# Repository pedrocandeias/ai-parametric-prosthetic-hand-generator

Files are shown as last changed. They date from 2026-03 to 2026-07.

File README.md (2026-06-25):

# AI Parametric Prosthetic Hand Generator

**🌐 Languages: English · [Português](README.pt.md)**

**🔗 Live: [handfab.pedrocandeias.net](https://handfab.pedrocandeias.net)**

AI-powered parametric prosthetic hand customisation platform. Clinicians enter a patient's anthropometric measurements; an AI model (Claude or GPT-4) suggests optimal design parameters; the result renders in-browser via WebAssembly and exports as STL for 3D printing.

Built on [OpenSCAD](https://openscad.org/) and the [OpenSCAD Playground](https://github.com/openscad/openscad-playground) WASM runtime.

---

## Features

- **In-browser 3D rendering** — OpenSCAD runs entirely in WebAssembly; no server round-trip for rendering
- **AI parameter suggestions** — Claude or GPT-4 analyses anthropometric input and recommends parameter values
- **Six canonical anthropometric parameters** — all models share the same measurement definitions (`palm_breadth_mm`, `palm_length_mm`, `palm_thickness_mm`, `middle_finger_length_mm`, `thumb_length_mm`, `gauntlet_width_mm`) so patient profiles auto-populate model inputs
- **Saved configurations** — named parameter sets stored per patient; load across sessions
- **Multi-user RBAC** — Admin / Tech / User roles; techs manage assigned patients
- **Secure API proxy** — AI keys live server-side only
- **STL export** — download print-ready files directly from the browser; models with defined parts offer a selection modal to export the whole model or individual parts (multiple parts download as a ZIP). On the Flexy Beast, each finger splits into a separate **base** and **tip** piece so every printable component can be exported and oriented on its own
- **Admin SCAD code editor** — admins can hand-edit OpenSCAD source and render immediately
- **Anthropometric profile library** — import population-level hand measurement datasets; geometry parameters are auto-derived and mapped to model inputs
- **Bulk CSV import** — load a population hand-measurement dataset (e.g. the `multi_population_hand.csv` research dataset, ~96 groups) through your browser's file picker in one click. The import reads the file locally and uploads its contents; re-running is safe (duplicate groups are skipped)
- **Multilingual (EN/PT)** — a language switcher translates the whole interface (app, configurator, admin panel) and the model/parameter text; the active language is detected from the browser and remembered. Adding a language is a single dictionary file
- **Editable footer & content pages (CMS)** — admins manage the footer and create Markdown pages (Privacy, Terms, Help, …) from the Admin Panel; pages render at clean `/pages/<slug>` URLs, and each page can be translated into a linked per-language version

---

## Available Models

| Model | ID | Parameters | Notes |
|---|---|---|---|
| **Flexy Beast** | `flexy_beast` | All anthropometric params + flexy-joint hardware + grip pads + forearm gauntlet | Fully parametric, self-contained — no external STL imports |
| **UnLimbited Phoenix Hand V1.0** | `unlimbed_phoenix_hand` | Uniform print scale derived from `palm_breadth_mm` (Team UnLimbited HandPerc); per-part selector | STL-derived meshes; 8 printable pieces (palm, fingers, phalanx, pins, tension box/pins, gauntlet, jig) |
| **Paraglider Hand (Flexible Flyer)** | `paraglider_hand` | All anthropometric params + per-finger scaling + assembled/print-layout views + `show_*` part toggles | Parametric fingers; palm imports a repaired Phoenix v2 mesh as its base body |
| **Paraglider variants & accessories** | `paraglider_palm_v3`, `paraglider_palm_reborn_tensor`, `paraglider_palm_v3_tensor`, `paraglider_tensioner_box`, `paraglider_thermo_gauntlet`, `paraglider_unlimbited_arm` | Palm variants (Phoenix Reborn / UnLimbited v3, integrated-tensioner), tensioner box, thermoform gauntlet, elbow-powered arm | Marcus Mendenhall's Paraglider remix family; uniform print scale from canonical `palm_breadth_mm` (the arm keeps native `HandLen` mm) |

---

## Requirements

- **Node.js ≥ 22** — the database uses Node's built-in `node:sqlite`, so no native module needs compiling
- An Anthropic or OpenAI API key (for AI suggestions; the app works without one but the suggestion button is disabled)

---

## Getting Started

### 1. Install

```bash
git clone <repo>
cd ai-parametric-prosthetic-hand-generator
npm install
```

### 2. Configure

```bash
cp .env.example .env
```

Edit `.env`:

```env
JWT_SECRET=<run: node -e "console.log(require('crypto').randomBytes(32).toString('hex'))">
ANTHROPIC_API_KEY=sk-ant-...
OPENAI_API_KEY=sk-...
PORT=3000
NODE_ENV=production
```

`JWT_SECRET` is required — the server will not start without it.

### 3. Start

```bash
npm start          # production
npm run dev        # development (auto-restarts on file change)
```

### 4. First-run setup

Navigate to `http://localhost:3000`. The app shows a **First-Run Setup** form — create the admin account. You can then create tech and user accounts from the Admin Panel.

**CLI alternative:**

```bash
node scripts/create-admin.js admin admin@example.com MyPassword123
```

---

## Deployment

The app is a single Node.js process that serves both the REST API and the static
frontend, so deploying means shipping the source tree (minus secrets, the dev
database, and `node_modules`) and running `npm ci` + `npm start` on the server.

The live site runs on **cPanel + Phusion Passenger** (Node 24). There is no build
step — `app.js`, `models/`, and the `.scad` files ship as-is. The everyday deploy
is a single command:

```bash
./deploy.sh deploy --dry-run     # preview exactly what will transfer (no changes)
./deploy.sh deploy               # → configured cPanel target, after a remote DB+code backup
```

With **no destination** it uses the configured cPanel target; the script stages
the tree, takes a remote backup (DB + code tarball), then rsyncs. Useful flags:
`--port N` (SSH port), `--yes` (skip the confirm prompt), `--delete` (mirror —
removes stale remote files, use with care). To target a different host, pass
`user@host:/path` explicitly. Use `./deploy.sh collect --tar` to stage a
`deploy.tar.gz` locally without uploading.

The package **excludes** secrets (`.env`), the dev SQLite DB (`data/`),
`node_modules`, `.git`, tests, and — critically — the server-managed
**`.htaccess`** (it holds the Passenger config and the COOP/COEP headers the
OpenSCAD WASM needs). A post-stage safety check aborts if a secret or `data/`
slips through. `.env.example` *is* included as a template.

**After a deploy:** client-only changes (`app.js`, `index.html`, `models/`,
`.scad`) are live as soon as the browser refetches. Changes under `server/**`
need a **Restart** in the cPanel "Setup Node.js App" panel; new dependencies also
need **Run NPM Install** there.

First-time server setup (create the cPanel Node app, set `JWT_SECRET` + API keys,
`npm ci`, `create-admin`) and a pm2 + Nginx VPS alternative are covered in
[DEPLOYMENT.md](DEPLOYMENT.md) and [DEPLOY-QUICKSTART.md](DEPLOY-QUICKSTART.md).

---

## Project Structure

```
/
├── index.html                  Main UI
├── auth.js                     Frontend auth (token in memory, refresh cookie)
├── app.js                      ParameterEditor — rendering, UI, save/load
├── admin.html / admin.js       Admin panel (users, anthropometric, footer & pages)
├── anthropometric.js           Anthropometric importer modal (admin)
├── openscad-worker.js          WASM rendering worker
├── page.html                   Public Markdown content-page viewer (/pages/<slug>)
├── i18n.js / translations.js   Lightweight i18n core + EN/PT dictionaries
├── footer.js                   Renders the editable footer from the API
├── markdown.js                 Tiny safe Markdown → HTML renderer
│
├── models/
│   ├── models-config.json                  Model registry + parameter specs (with _pt translations)
│   └── active/
│       ├── flexy_beast/                     Flexy Beast — self-contained parametric SCAD
│       ├── unlimbed_phoenix_hand/           UnLimbited Phoenix Hand — STL-derived, per-part export
│       ├── paraglider_hand/                 Paraglider Hand — parametric SCAD + palm mesh base
│       └── paraglider/                      Paraglider variants & accessories (palms, tensioner, gauntlet, arm)
│
├── docs/                           Model notes + anthropometric validation
│
├── data/                          (gitignored — created/supplied locally, not in the repo)
│   ├── app.db                      SQLite DB (auto-created on first run)
│   └── multi_population_hand.csv   Population hand measurements (~96 groups; supply separately)
│
├── server/
│   ├── index.js                Express server entry point
│   ├── db.js                   node:sqlite connection (auto-migrates)
│   ├── schema.sql              DB schema
│   ├── middleware/             auth.js, errorHandler.js
│   ├── routes/                 setup, auth, users, configs, ai, anthropometric, content
│   └── services/              authService.js, aiService.js, anthropometricImporter.js
│
├── scripts/
│   ├── create-admin.js         CLI admin creation
│   └── seed-content.js         Seed/refresh the footer + content pages
│
├── CLAUDE.md                   Developer guide for Claude Code
├── CHANGELOG.md                Version history
├── .env.example                Environment template
└── package.json
```

---

## User Roles

| Role | Capabilities |
|---|---|
| **admin** | Full access: manage users, view all configs, tech assignments, SCAD code editor |
| **tech** | Own configs + read/write configs for assigned patients |
| **user** | Own saved configurations only |

---

## Anthropometric Parameters

All models that support auto-population from patient profiles use these canonical parameter names:

| Parameter | Measurement | Typical adult range |
|---|---|---|
| `palm_breadth_mm` | Knuckle-to-knuckle metacarpal breadth | 70–100 mm |
| `palm_length_mm` | Wrist base to MCP knuckle line | 90–120 mm |
| `palm_thickness_mm` | Palmar to dorsal surface | 22–38 mm |
| `middle_finger_length_mm` | MCP crease to middle fingertip | 60–100 mm |
| `thumb_length_mm` | Thumb MCP crease to tip | 45–80 mm |
| `gauntlet_width_mm` | Forearm socket width (≈ wrist circumference / π) | 40–90 mm |

These names must match exactly in `.scad` files and `models-config.json` so patient profiles imported from CSV auto-populate the correct fields.

### Importing the population dataset

The dataset CSV is **not bundled in the repo** (`data/` is gitignored). Obtain
`multi_population_hand.csv` separately and place it anywhere on your machine first.

1. Log in as admin → open **Admin Panel**
2. Go to **Anthropometric Profiles** tab
3. Click **⬆ Import CSV Dataset** — your browser opens a file picker. Browse to wherever you
   saved `multi_population_hand.csv` (in this project it lives at `data/`) and choose it. The
   file is read locally in the browser and its contents are uploaded; the app does not fetch it
   by path.
4. A confirmation shows how many profiles were created (re-importing is safe — duplicate groups
   are skipped)

> The CSV must conform to the bulk-import schema (columns `measurement_name`, `population`,
> `country`, `sex`, `age_group`, `stat_type`, `value_mm`, …); only `mean` rows are imported.
> See [docs/ai_anthropometric_validation.md](docs/ai_anthropometric_validation.md) Appendix C
> for the full pipeline.

---

## Adding a Model

1. Place your `.scad` file in `models/`
2. Add an entry to `models/models-config.json`:

```json
{
  "id": "my_model",
  "name": "My Prosthetic Model",
  "description": "...",
  "file": "my_model.scad",
  "parameters": [
    {
      "name": "palm_breadth_mm",
      "type": "number",
      "initial": 83,
      "min": 55,
      "max": 110,
      "step": 1,
      "caption": "Knuckle-to-knuckle palm breadth (mm)",
      "group": "Anthropometric"
    }
  ]
}
```

3. Restart the server — the model appears in the dropdown immediately.

**Parameter types:**

| Type | Control | Notes |
|---|---|---|
| `number` with `min`/`max` | Slider | |
| `number` without `min`/`max` | Number input | |
| `boolean` | Checkbox | |
| `string` | Text input | |

If the model references external STL files via `import()` or `use<>`, list them under `dependencies`:

```json
"dependencies": [
  { "url": "subdir/part.stl", "path": "part.stl" }
]
```

The `url` is relative to `models/` on the server; `path` is where the file lands in the WASM virtual filesystem (must be flat — no subdirectories).

---

## API Overview

| Endpoint | Description |
|---|---|
| `GET /api/setup/status` | First-run check |
| `POST /api/setup/admin` | Create first admin |
| `POST /api/auth/login` | Login |
| `POST /api/auth/register` | Self-register |
| `POST /api/auth/refresh` | Rotate tokens via cookie |
| `POST /api/auth/logout` | Revoke refresh token |
| `GET /api/users` | List users (admin) |
| `POST /api/users` | Create user (admin) |
| `GET /api/configurations` | List accessible configs |
| `POST /api/configurations` | Save config |
| `PUT /api/configurations/:id` | Update config |
| `DELETE /api/configurations/:id` | Delete config |
| `POST /api/ai/suggest` | AI parameter suggestion proxy |
| `GET /api/anthropometric` | List anthropometric profiles (admin) |
| `POST /api/anthropometric` | Create profile from manual/CSV/JSON (admin) |
| `POST /api/anthropometric/import-csv-bulk` | Bulk-import population CSV (admin) |
| `GET /api/anthropometric/:id` | Fetch profile with derived geometry params |
| `PUT /api/anthropometric/:id` | Update profile |
| `DELETE /api/anthropometric/:id` | Delete profile |
| `GET /api/content/footer` · `PUT` | Read footer config (public) / save (admin) |
| `GET /api/content/pages/:slug?lang=` | Public content page, language-aware |
| `POST/PUT/DELETE /api/content/pages` | Manage content pages (admin) |
| `POST /api/content/pages/:id/translate` | Create a linked translation of a page (admin) |

**Rate limits:** login 5/15 min · register 3/hr · AI suggestions 10/min · all others 500/15 min

---

## Security

- Passwords hashed with bcrypt (cost 12)
- JWT access tokens: 15-minute expiry, stored in JS memory only (never localStorage)
- Refresh tokens: 7-day expiry, stored as SHA-256 hashes, rotated on every use
- `/.env` and `/config.json` return 404 — blocked before static middleware
- All request bodies validated with Zod
- Helmet CSP headers
- AI API keys never leave the server

---

## Configuration Reference

| Variable | Required | Description |
|---|---|---|
| `JWT_SECRET` | Yes | 64-char hex string for JWT signing |
| `ANTHROPIC_API_KEY` | For AI | Claude API key |
| `OPENAI_API_KEY` | For AI | OpenAI API key |
| `PORT` | No | HTTP port (default: 3000) |
| `NODE_ENV` | No | `development` or `production` |

---

## Password Reset (CLI)

```bash
node -e "
const db = require('./server/db');
const bcrypt = require('bcrypt');
const hash = bcrypt.hashSync('newpassword', 12);
db.prepare('UPDATE users SET password_hash = ? WHERE username = ?').run(hash, 'admin');
console.log('done');
"
```

---

## Credits

- [OpenSCAD Playground](https://github.com/openscad/openscad-playground) — WASM rendering runtime
- [OpenSCAD](https://openscad.org/) — parametric 3D modelling language
- [Flexy Beast](https://www.thingiverse.com/thing:380665) by daprice — a mashup of the Parametric Cyborg Beast and the Flexy Hand
- [Team UnLimbited](https://www.thingiverse.com/thing:1672381) — UnLimbited Arm / Phoenix Hand designs
- [e-NABLE](https://enablingthefuture.org) — open-source prosthetic hand designs (Phoenix / Unlimbited lineage behind the Paraglider Hand)

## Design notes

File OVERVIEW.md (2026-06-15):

# Project Overview

## What This Project Does

A web application for clinicians and prosthetists to:

1. Load parametric OpenSCAD prosthetic hand models
2. Edit parameters using auto-generated sliders, checkboxes, and inputs
3. Preview the 3D model in real-time (rendered in-browser via OpenSCAD WebAssembly)
4. Get AI-suggested parameter values from a patient's anthropometric data
5. Save named configurations per patient and load them later
6. Export customised models as STL files ready for 3D printing — whole model or individual print pieces (on the Flexy Beast, each finger as a separate base and tip)

Multi-user support with three roles: **Admin**, **Tech** (prosthetist), and **User** (patient). Techs can see and edit configurations for their assigned patients.

---

## Architecture at a Glance

```
┌──────────────────────────────────────────────────┐
│  Browser                                          │
│                                                   │
│  index.html  auth.js  app.js  openscad-worker.js  │
│   (UI)       (auth)  (logic)  (WASM rendering)    │
└───────────────────┬──────────────────────────────┘
                    │  HTTP/REST
┌───────────────────▼──────────────────────────────┐
│  Node.js / Express  (server/index.js)             │
│                                                   │
│  /api/setup  /api/auth  /api/users                │
│  /api/configurations  /api/ai  /api/anthropometric│
│                                                   │
│  Helmet · Rate limits · Cookie parser             │
└──────────┬──────────────────┬────────────────────┘
           │                  │
    ┌──────▼──────┐    ┌──────▼──────┐
    │  SQLite DB  │    │  AI APIs    │
    │  data/app.db│    │  Anthropic  │
    │             │    │  OpenAI     │
    └─────────────┘    └─────────────┘
```

**Key design decisions:**

- OpenSCAD rendering is 100% client-side (WebAssembly). No server load for 3D rendering.
- The server handles auth, persistence, and AI proxying only.
- AI API keys are server-side only — clients never see them.
- Access tokens live in JavaScript memory (not localStorage) for XSS resistance.
- Refresh tokens are stored in HttpOnly cookies (CSRF-resistant via SameSite=Strict).

---

## Key Components

### Frontend

| File | Purpose |
|---|---|
| `index.html` | Single-page app shell — login modal, sidebar, 3D viewer |
| `auth.js` | `Auth` singleton: login, logout, token storage, silent refresh, `fetchWithAuth` |
| `app.js` | `ParameterEditor` class: model loading, parameter UI, rendering, save/load configs |
| `admin.html` / `admin.js` | Admin panel: user management, tech assignments |
| `openscad-worker.js` | Web Worker that runs OpenSCAD WASM for rendering |

### Backend

| File | Purpose |
|---|---|
| `server/index.js` | Express app — security middleware, route mounting, static serving |
| `server/db.js` | SQLite connection, auto-applies `schema.sql` on startup |
| `server/services/authService.js` | bcrypt hashing, JWT sign/verify, refresh token management |
| `server/middleware/auth.js` | `requireAuth` and `requireRole()` middleware factories |
| `server/routes/setupRoutes.js` | First-run admin creation (hard-gated) |
| `server/routes/authRoutes.js` | login, register, logout, refresh, me |
| `server/routes/userRoutes.js` | User CRUD + tech-patient assignments |
| `server/routes/configRoutes.js` | Saved configuration CRUD with ownership enforcement |
| `server/routes/aiRoutes.js` | Authenticated proxy to Anthropic/OpenAI |
| `server/routes/anthropometricRoutes.js` | Anthropometric profile CRUD + CSV/JSON import (admin) |
| `server/services/aiService.js` | Server-side HTTPS calls to AI providers |
| `server/services/anthropometricImporter.js` | Parses measurement datasets, derives geometry parameters |

### Data

| Table | Purpose |
|---|---|
| `users` | Accounts (username, email, bcrypt hash, role, active flag) |
| `tech_assignments` | Many-to-many tech ↔ patient relationships |
| `configurations` | Named saved parameter sets (JSON blob per row) |
| `refresh_tokens` | Hashed refresh tokens with expiry and revocation |
| `anthropometric_profiles` | Population/patient hand measurements + derived geometry |
| `password_reset_tokens` | One-time, hashed password-reset tokens with expiry |

---

## User Roles

| Role | Can do |
|---|---|
| **admin** | Manage all users, view/edit all configs, assign techs to patients |
| **tech** | View and edit configs for their assigned patients + own configs |
| **user** | View and edit own configs only |

---

## AI Integration

AI calls originate from the **server**, not the browser. The flow is:

1. User types anthropometric data (e.g. `woman, 42yo, 172cm, 75kg, arm 65cm`)
2. `app.js` builds a prompt including current model parameters
3. POST `/api/ai/suggest` — server authenticates the user, applies rate limit
4. `server/services/aiService.js` calls Anthropic or OpenAI using env-var API keys
5. JSON parameter suggestions are returned to the browser and applied to the UI

API keys are read from `process.env` only and are never sent to the client.

---

## OpenSCAD Rendering

Rendering is fully client-side:

1. Parameter controls update the OpenSCAD source code string (in memory)
2. The code is sent to `openscad-worker.js` via `postMessage`
3. The worker runs OpenSCAD WASM, outputs an `.off` mesh
4. `app.js` converts the `.off` to a `.glb` binary
5. `<model-viewer>` displays the result with camera controls

No server involvement. Typical render time: 500ms – 3000ms depending on model complexity.

---

## Technology Stack

| Layer | Technology |
|---|---|
| Runtime | Node.js ≥ 22 |
| HTTP framework | Express 4 |
| Database | SQLite via Node's built-in `node:sqlite` |
| Auth | bcrypt + JWT (HS256) + HttpOnly cookies |
| Validation | Zod |
| Security headers | Helmet |
| Rate limiting | express-rate-limit |
| 3D rendering | OpenSCAD WebAssembly + Google model-viewer |
| Frontend | Vanilla JavaScript (no framework) |

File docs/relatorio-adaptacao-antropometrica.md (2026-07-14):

# Relatório — Adaptação paramétrica dos modelos aos dados antropométricos

**Projeto:** AI Parametric Prosthetic Hand Generator
**Âmbito:** análise técnica detalhada do que foi **adicionado e modificado** em cada modelo ativo da plataforma para que (a) fiquem paramétricos e (b) os dados antropométricos do paciente lhes possam ser aplicados.
**Exclusão:** este relatório não cobre o modelo **pec Phoenix** (por indicação; tem relatório próprio em `docs/pec-phoenix-hand/`).

> As afirmações citam ficheiros reais e versões do `CHANGELOG.md`. A história git está compactada em poucos commits, pelo que a atribuição de versões usa os blocos datados do CHANGELOG (a fonte fiável), cruzados com o conteúdo atual dos ficheiros.

---

## 1. Contexto e problema

Os modelos herdados são reconstruções de designs da comunidade e-NABLE (Flexy Beast, Cyborg Beast, UnLimbited Phoenix, Paraglider/Flexible Flyer). No estado original **não** consumiam medições antropométricas: apresentavam escala fixa ou hardcoded, nomes de parâmetro incompatíveis com o pipeline de importação, e acoplamentos escondidos (partes com escala congelada dentro de sub-ficheiros, percursos de dimensionamento com limites inconsistentes).

O trabalho tornou cada modelo **paramétrico e ancorado na anatomia do paciente**, mantendo os **nomes de campo canónicos** de `CLAUDE.md` (secção *Anthropometric Parameter Alignment*), de forma a que um perfil importado (CSV → base de dados) auto-preencha os parâmetros corretos.

Duas estratégias de parametrização emergiram, consoante a natureza da geometria herdada:
- **Geometria própria escalável** (Flexy Beast, Cyborg Beast) — reconstruída em SCAD paramétrico; a escala aplica-se diretamente às primitivas.
- **Meshes fixas importadas** (UnLimbited Phoenix; a palma do Paraglider) — a camada paramétrica é construída *à volta* das meshes sem distorcer as zonas funcionais (furos de pino), esticando só bandas sem furos.

---

## 2. A ponte de dados — `server/services/profileMapping.js`

O elo entre o **perfil antropométrico armazenado** e o **modelo paramétrico vivo** é `profileMapping.js` — a **única fonte de verdade** desta tradução, usada tanto pelo seletor "Population baseline" da configuração como pelo grounding da IA (`aiRoutes.js`).

**Decisão de arquitetura chave:** o mapeamento parte da árvore anatómica normalizada `profile.measurements` (ex.: `palm.width_mm`, `digits.middle.total_length_mm`) e **não** dos `geometry_parameters` do importador. Estes foram construídos para o design socket-and-phalanx Kwawu/cyborgbeast (chaves como `finger_length_index`, bloco `pekwawu`) e **nenhum** coincide com os nomes canónicos dos modelos. A `profile.measurements` alinha 1:1 com a coluna "Platform source" de `CLAUDE.md`.

Mapa canónico (`PARAM_TO_MEASUREMENT_PATH`):

| Parâmetro do modelo | Caminho em `profile.measurements` |
|---|---|
| `palm_breadth_mm` | `palm.width_mm` |
| `palm_length_mm` / `palm_thickness_mm` | `palm.length_mm` / `palm.thickness_mm` |
| `index/middle/ring/pinky_finger_length_mm` | `digits.<dedo>.total_length_mm` |
| `thumb_length_mm` | `digits.thumb.total_length_mm` |
| `*_base_length_mm` (proximal) | `digits.<dedo>.proximal_length_mm` |
| `wrist_circumference_mm` | `wrist.circumference_mm` |

`mapProfileToModelParameters(profile, modelDef)` percorre os parâmetros do modelo e só aplica um valor quando este (a) existe no modelo, (b) é numérico, (c) está no mapa canónico e (d) tem uma medição finita — fazendo **clamp aos min/max** declarados. Parâmetros não anatómicos (hardware, visibilidade, lateralidade, cores) nunca são tocados.

---

## 3. Análise detalhada por modelo

### 3.1 Flexy Beast

**Origem e estado herdado.** Adaptado de `daprice/Flexy-Beast` (CC BY-SA 4.0), ele próprio um mashup do Parametric Cyborg Beast (MakerBlock) e do Flexy Hand (Steve Wood / Gyrobot) — juntas flexíveis impressas substituem os parafusos Chicago e elásticos. O design upstream tinha escala fixa e não expunha inputs anatómicos; a charneira dos dedos era uma placa STL medida (`Finger_Hinge_Plate.scad` traçado de `Finger_Hinge_Plate.stl`) e o gauntlet era uma mesh importada opaca. Entrou na plataforma **já paramétrico** em **v9.1.0** (self-contained, sem imports STL, geometria conduzida por parâmetros canónicos).

**Ficheiros.** `models/active/flexy_beast/flexy_beast.scad` (auto-contido: palma, dedos, polegar, liner termoformável, juntas flexíveis); `gauntlet.scad` (cópia do Cyborg desde v14.70 — ver §5); fontes de reconstrução dev-only em `models/reconstruction/flexy_beast/` (excluídas do deploy).

**Mecanismo de escala** (`flexy_beast.scad`):
- **Escala uniforme da mão** — guia de tamanhos Cyborg Beast:
  ```
  xScaleFactor = (palm_breadth_mm + 5) / 55;   // isotrópico (y=z=x)
  ```
  Palma (`cyborgbeastpalm`), polegar, cutouts de hardware e abas de pulso são todos envolvidos em `scale([xScaleFactor,…])`.
- **Comprimento dos dedos** — âncora anatómica: a scale=1 o alcance é `fingerbase(20)+fingertip_curved(17)=37 mm`, codificado como `REF_FINGER_MM=37` e invertido:
  ```
  fingerLength = middle_finger_length_mm / (REF_FINGER_MM * xScaleFactor);
  ```
  (é o multiplicador *residual* de comprimento sobre a escala uniforme, para o dedo médio alcançar `middle_finger_length_mm` a qualquer escala de palma.)
- **Proporções por dedo** relativas ao médio: `indexProp = index_finger_length_mm / middle_finger_length_mm` (idem ring/pinky/thumb). Cada dedo é emitido como `fingerlayout(<prop>·fingerLength)`, que escala os dois segmentos (base 20 mm, tip 17 mm) pelo mesmo multiplicador.
- **Colocação derivada** (não hardcoded): os quatro dedos numa pitch `sp=14` × `xScaleFactor`, na linha dos nós; o polegar reutiliza a geometria dos dedos via `thumbProp`.

**Parâmetros antropométricos** (6 canónicos, grupo `Anthropometric`): `palm_breadth_mm` (→ `xScaleFactor`), `middle_finger_length_mm` (→ `fingerLength` e denominador dos `*Prop`), `index/ring/pinky_finger_length_mm` (→ `*Prop`), `thumb_length_mm` (→ `thumbProp`). **Não** usa o split proximal/distal (base/tip derivam como frações fixas 20/17 de um multiplicador). `mirrored` (`role:"laterality"`).

**Juntas flexíveis (v14.34).** A placa STL medida foi substituída por um `flexy_joint()` paramétrico (dogbone de duas lobas + membrana flexível), com todas as dimensões derivadas do hardware (`joint_dia`, `joint_thick`) e da escala.

**Versões-chave:** v9.1.0 (add paramétrico); v11.0.0 (correção da ponte perfil→modelo, remoção do `applyGeometryParameters` morto); v13.1–13.2 (gauntlet + charneira de pulso); v14.34 (`flexy_joint()`); **v14.70 (gauntlet partilhado com o Cyborg — §5)**.

### 3.2 Cyborg Beast

**Estado herdado.** Cyborg Beast MakerBlock / e-NABLE (parafusos Chicago + cordão elástico). Três módulos originais foram `include`d praticamente intactos: `cyborgpalm001.scad` (palma; `hardwarecutouts()` já define os eixos de charneira do nó em `y=27` e do pulso em `y=-27, z=5.5`), `cyborgfingermid002.scad` (falange proximal `fingermid`, com alavanca nativa `len` e furos em `±(11.5+len/3)`), `cyborgfingertip002.scad` (falange distal). Toda a camada paramétrica vive no wrapper **`cyborg_beast.scad`** (novo, v14.32.0).

**Escala:**
```
overall_scale = (palm_breadth_mm + 5) / 55;   // aplicado no topo: scale(overall_scale)
```
Curva de alcance medida (por-dedo, via `len`):
```
R(len) = 60.85 + 1.584·len   (len ≥ 0)
R(len) = 60.85 + 1.328·len   (len < 0)
```

**Divisão proximal/distal (v14.37 — a funcionalidade antropométrica de topo).** Cada segmento impresso ganhou a sua própria alavanca: base → `lp` (`fingermid`), tip → `ld` (`fingertip`). O vão proximal é **analítico**:
```
vão proximal (MCP→PIP) = 23 + (2/3)·lp
```
O alcance distal é resolvido **por diferença** para o comprimento total se manter (`DREACH0 = 60.85 − 23 = 37.85`), com funções de inversão `base_lp(base_mm)` / `tip_ld(total_mm, base_mm)`. `place_finger()` assenta o dedo na linha dos nós com `yoff = 9.5 + lp/3` (v14.35), mantendo o pino coaxial para qualquer split. Com `lp==ld` reduz-se exatamente ao dedo nativo (render retrocompatível).

O **polegar** é calibrado por render (escala uniforme do sub-conjunto): `reach_local = 55.84 + 0.6185·lp + 0.77·ld` (ajuste em grelha 5×4, resíduo máx. 0.74 mm); `thumb_scale()` preserva o comprimento total.

**Parâmetros antropométricos:** `palm_breadth_mm` (→ `overall_scale`), comprimentos totais dos dedos, `thumb_length_mm`, e **`*_base_length_mm` → `digits.<f>.proximal_length_mm`** (o split), e `wrist_circumference_mm` (gauntlet). **Descoberta:** o schema do importador (`anthropometricImporter.js`) já definia `digits.<f>.proximal/middle/distal_length_mm` (rácios `PHALANX_RATIOS` 0.45/0.31/0.24; polegar 0.54/0.46) mas **nunca fora ligado a nenhum SCAD** — o split plumbou-o pela primeira vez.

**Gauntlet (v14.40).** `gauntlet.scad` reconstrói o *Normal Gauntlet with Tensioner* como **polyhedron orgânico embebido** (~8000 faces, ~99% do volume; sem import STL), com os furos re-cortados parametricamente (argumentos de módulo, não globais). Dimensionamento anisotrópico `[g_hinge, g_len, g_depth]`:
```
g_hinge = (G_FIN_X − 2.6) / G_PRONG_X          // X fixo à palma (prongs 2.6 mm dentro das abas)
g_depth = (wrist_circumference_mm/π + 6) / (G_NATIVE_W · overall_scale)   // girth ao pulso
g_len   = gauntlet_length_scale
```
Auto-assenta no eixo do pino do pulso (`G_PIN_Y=-27, G_PIN_Z=5.5`) resolvendo `g_seat` após a rotação/escala, para qualquer girth/comprimento/tilt. Registado como dependência para o loader WASM. Parâmetros: `show_gauntlet`, `wrist_circumference_mm`, `gauntlet_tilt`, `gauntlet_length_scale`, `wrist_pin_dia`/`wrist_pin_clearance`, `gauntlet_rim_hole_d`.

**Calibração do polegar (v14.44).** Medição vs. STLs de referência (`Thumb_Phal.stl`=31.2 mm, `Thumb_Finger_w_Bumps.stl`=36.5 mm) mostrou a base ~6 mm curta; correção: `THUMB_BASE_REACH` 44.93→51.3 mm e default `thumb_base_length_mm` 22→27 → base e tip a <0.1 mm dos originais.

**Versões-chave:** v14.32 (wrapper antropométrico), v14.35 (assentamento), v14.37 (split), v14.40/14.41 (gauntlet), v14.44 (polegar).

### 3.3 Paraglider · Hand Reborn

**Estado herdado.** Base "Flexible Flyer"/Paraglider de Marcus Mendenhall (2020, CC BY-SA 4.0). A palma **não** é geometria procedural pura — assenta numa mesh importada (`palm_left_v2_nobox.stl`, mesh Phoenix v2) mais furação/canais processados. Upstream usava `overall_scale=1.25` hardcoded por ficheiro, e construções `each`/`[[..],,[..]]` incompatíveis com o WASM (corrigidas).

**Ficheiros:** `paraglider_hand.scad` (wrapper autorado), `paraglider_palm_left.scad` (palma Reborn, `scaled_palm()`), `fingerator.scad`, `pipe.scad`, `pg_v3palm.scad` (palma UnlimbitedV3), `pg_box/gauntlet/arm.scad` (componentes namespaced via `scripts/namespace_scad.py`). Distinção crítica: o wrapper puxa a palma Reborn com **`use`** (âmbito lexical) e a V3 com **`include`**.

**Escala:**
```
overall_scale = palm_breadth_mm / 66.4;                  // REF_PALM=66.4 (default 83 → 1.25)
global_scale  = middle_finger_length_mm / 57.6;          // REF_FINGER=57.6 (72 → 1.25)
index_scale   = index_finger_length_mm  / 57.6;          // idem ring/pinky
```
Cada dedo escala pelo seu próprio comprimento (recebe `fscale` como argumento de módulo → `_sf = fscale/global_scale`); os furos de pino são divididos de volta (`d/scale_size`) para manterem tamanho físico constante.

**Bug corrigido (v14.17).** A palma Reborn **não** escalava com `palm_breadth_mm` — congelada em 113.70×100.80×38.19 mm (o tamanho 83 mm à escala 1.25) para qualquer largura. **Causa:** `scaled_palm()` vive em `paraglider_palm_left.scad` (que assa `overall_scale=1.25`) e era puxada com `use` (lexical), ignorando o `overall_scale` do wrapper; os dedos escapavam por receberem a escala como argumento. **Correção:** `scale(overall_scale / 1.25) scaled_palm()` no call site. Verificado: 62→84.9, 83→113.7 (inalterado), 96→131.5 mm. A palma UnlimbitedV3 já estava correta (`include`).

**Parâmetros antropométricos.** `palm_breadth_mm` (deforma a palma), `index/middle/ring/pinky_finger_length_mm` (deformam os dedos). **Nota honesta:** só **5 dos 8** campos canónicos deformam geometria — `palm_length_mm`, `palm_thickness_mm` e `thumb_length_mm` são armazenados para alinhamento perfil/IA mas não reesculpem a mesh (a palma é escalada uniformemente pela largura; o polegar segue o `global_scale`). `mirrored` (`role:"laterality"`).

**Componentes (v14.11).** Consolidado de 7 modelos separados num só com seletores `component` (Hand/Box/Gauntlet/Arm) e `palm_style` (Reborn/UnlimbitedV3). Os acessórios `ARM_*`/`GAU_*` usam dimensões nativas próprias, não o conjunto canónico (não são conduzidos pelas medidas do paciente).

**Versões-chave:** v7.0/7.1 (ativação paramétrica + alinhamento canónico), v7.7 (comprimento por dedo), v14.11 (consolidação), v14.17 (correção da escala da palma).

### 3.4 UnLimbited Phoenix

**Estado herdado.** Team UnLimbited Phoenix Hand V1.0 (Davies & Murray; Phoenix original de Jason Bryant; CC BY-NC-SA). O ficheiro pristino está preservado em `UnLimbitedPhoenix_original.scad`. Superfície paramétrica mínima: seletor `part`, uma escala global `HandPerc` (100–160%), e `LeftRight`. As **meshes são fixas** (STL/polyhedron embebidos), por isso a estratégia foi construir a camada paramétrica *à volta* delas sem distorcer os furos de pino.

**Ficheiros (dependências registadas para o loader WASM):** `UnLimbitedPhoenix.scad` (servido), `phoenix_assembly.scad` (receita partilhada), `phoenix_preview_meshes.scad` (meshes manifold para a preview), `phoenix_snap_pins.scad`, `phoenix_tensioner_block.scad`, `phoenix_tensioner_pins.scad` (reconstruções B-rep medidas do STEP via step2scad).

**Escala da palma:**
```
HandPerc = HandPerc_override > 0
    ? max(100, min(160, HandPerc_override))
    : max(100, min(160, palm_breadth_mm / 82 * 100));   // REF_PALM_BREADTH = 82
```
O render final aplica `scale([HandPerc/100,…])`. A **correção v14.18** clampou **ambos** os percursos a 100–160% (a banda `1–99` do override era uma zona morta sem piso — na simulação de IA uma criança saía a 76%/62 mm).

**Comprimento paramétrico por dedo (v14.48) — o núcleo antropométrico.** Como as meshes são fixas e têm furos, um dedo é alongado esticando **só a banda de haste sem furos**, mantendo as zonas de dobradiça intactas e empurrando a extremidade. Parâmetros `index/middle/ring/pinky/thumb_finger_length_mm` (total) + `*_base_length_mm` (proximal), com os nomes canónicos → auto-preenchidos por `profileMapping.js`. Referência nativa 72/31 (defaults renderizam idênticos ao dedo de série). Mecanismo em `phoenix_assembly.scad`:
```
REF_PROX = 31;  REF_DIST = 41;                 // 31 + 41 = 72
bd_of(i) = FBASE[i] − REF_PROX;                // extra proximal
td_of(i) = (FLEN[i] − FBASE[i]) − REF_DIST;    // extra distal

module stretch_shaft(ylo, yhi, d){             // 3 bandas em Y:
  intersection(){ children(); …acima de yhi… }               // extremidade de dobradiça: fixa
  translate([0,yhi,0]) scale([1,(yhi-ylo+d)/(yhi-ylo),1])…    // banda de haste: esticada
  translate([0,-d,0]) intersection(){ children(); …abaixo… }  // extremidade oposta: transladada
}
ph_col_s(i,bd) = stretch_shaft(20, 42, bd) …    // proximal: MCP fixo, PIP empurrado
fn_col_s(i,td) = stretch_shaft(-48,-14, td) …    // distal: PIP fixo, ponta empurrada
```
Como as zonas de furo nunca são escaladas (só fatiadas e mantidas/transladadas rigidamente), **os furos de pino ficam redondos**. O pino PIP e a ponta acompanham o proximal alongado (`translate([0,PIP_HOLE_Y+bd_of(f),…]) pin(…)`), mantendo a junta coaxial. Efeito 1:1 (médio 72→100 → alcance +27.6 mm).

**Componentização.** Preview de mão montada + `phoenix_assembly.scad` partilhado (v14.36); correções de manifold da preview (v14.41–14.45); toggles por peça `show_palm/fingers/thumb/pins/gauntlet/tensioner` + `print_layout` (v14.45); cores por peça `color_*` (v14.46).

**Parâmetros antropométricos:** `palm_breadth_mm`, comprimentos totais + `*_base_length_mm`. `mirrored` (`role:"laterality"` — ver §6). `HandPerc_override` (override manual de escala).

**Versões-chave:** v14.3 (integração + HandPerc), v14.18 (clamp), v14.36 (montagem + hardware STEP), v14.41–45 (preview manifold), v14.46 (cores), v14.48 (comprimento por dedo).

---

## 4. Correções transversais no pipeline IA/grounding

Não alteram geometria, mas garantem que os dados antropométricos certos chegam aos modelos.

- **Matcher de perfis (v14.16).** `findBestProfileMatch` ancorava quase todos os pacientes no *ANSUR I Male* (o token `'m,'` era substring de `"mm,"`/`"cm,"`; parsing só em inglês). Agora tokens em fronteiras `\b` Unicode e **multilingues (EN/PT/ES)**, idade entende "anos"/"años", `age_group` numérico bucketizado; mais extração LLM opcional de `{gender,age}` (`extractPatientAttributes`, `claude-haiku-4-5`) quando o parser determinístico falha.
- **Lateralidade UI-only (v14.19).** Uma avaliação UCD encontrou um defeito de segurança: a IA emitia `mirrored=true` independentemente do lado pedido. Agora os parâmetros de lado têm `role:"laterality"`; o `app.js` exclui-os da lista sugerível, injeta o lado escolhido como facto fixo, e descarta defensivamente qualquer chave de lateralidade em `applySuggestions`.

---

## 5. Unificação do gauntlet Flexy ↔ Cyborg (v14.70.0)

O Flexy Beast e o Cyborg Beast **partilham a palma do Cyborg Beast** — mesmo eixo do pino de pulso (`Y=-27, Z=5.5`), mesmas abas (`|X|=26.6`) e mesma fórmula de escala `(palm_breadth+5)/55`. Logo, **uma peça encaixa em ambos**. O gauntlet primitivo inline do Flexy (~120 linhas de módulos `g_*`) foi **removido** e substituído por uma cópia do `gauntlet.scad` orgânico do Cyborg (§3.2), com a matemática de assentamento portada verbatim, envolvida na escala uniforme do Flexy (`scale([xScaleFactor,…])`, equivalente ao `scale(overall_scale)` do Cyborg).

**Ganho antropométrico:** o gauntlet do Flexy trocou o antigo `gauntlet_width_mm` (não-canónico, derivado à mão pelo clínico) por **`wrist_circumference_mm`** (canónico) — passa assim a **auto-dimensionar-se do perfil do paciente** via `profileMapping.js`, tal como o Cyborg. Parâmetros unificados: `wrist_circumference_mm`, `gauntlet_tilt`, `gauntlet_length_scale`, `gauntlet_rim_hole_d`, `wrist_pin_dia`, `wrist_pin_clearance`.

Por decisão de projeto, o `gauntlet.scad` é **copiado** para o diretório de cada modelo (não partilhado por referência) para manter os modelos independentes. Verificado com renders OpenSCAD locais (montado, print layout, junta de pulso com furo redondo/coaxial, escala de criança).

---

## 6. Coerência de interface e normalização de parâmetros (v14.72.0)

Diagnóstico: os **nomes antropométricos já estavam alinhados** (é o propósito do §2); o que estava incoerente era a **organização da UI** — cada modelo ordenava os grupos de forma diferente e havia nomes divergentes para o mesmo conceito.

**Ordem canónica de grupos** (aplicada aos quatro modelos; grupos ausentes são saltados):
```
Component → Anthropometric → Segment split → Hardware → Gauntlet → Options → Visibility → Colors → Arm
```
O singleton "Palm liner" do Cyborg foi fundido em "Options". É uma reordenação **só de configuração** — nomes, valores e comportamento inalterados.

**Dois renames de normalização:**
- **Lateralidade:** Phoenix `LeftRight` (enum "Left"/"Right") → **`mirrored`** (boolean), igual aos outros três. `UnLimbitedPhoenix.scad` ramifica em `!mirrored`; a config usa o enum partilhado (Left=false/Right=true, `role:"laterality"`). **Sem migração necessária:** a lateralidade nunca é restaurada de configs guardadas (é saltada no `applySuggestions`), pelo que o rename não pode trocar silenciosamente uma mão guardada.
- **Toggle de vista:** Paraglider `show_assembled` (true=montado) → **`print_layout`** (true=plano), igual a Cyborg/Phoenix. `paraglider_hand.scad` ramifica em `print_layout`; o `exportLayout` do modelo passou a `{print_layout:true}`. É um toggle de pré-visualização, sobreposto no export — sem impacto geométrico em configs guardadas.

Ficam por normalizar apenas divergências **semânticas** legítimas (esquemas de cor/visibilidade por-segmento vs. por-dedo, conforme a geometria tenha 1 ou 2 segmentos; hardware específico como as juntas flexíveis) — forçar nomes idênticos aí pioraria a clareza.

---

## 7. Como foi validado

- **Simulação de sizing por IA → export STL** (Flexy, Paraglider, UnLimbited Phoenix) — revelou os bugs de escala/clamp/lateralidade. Relatórios em `tests/flexy-beast-ai-sim/`, `tests/paraglider-ai-sim/`, `docs/phoenix-ai-sim/`, `docs/ucd-ai-sim/`.
- **Provas dimensionais/MD5** dos STLs exportados (palma congelada do Paraglider; Phoenix mesh × HandPerc/100 a ≤0.06 mm; polegar do Cyborg a <0.1 mm dos STLs de referência).
- **Testes unitários herméticos** do matcher (`test/profileMapping.test.js`).
- **Testes E2E de export** (`tests/cyborg_export.spec.js`).
- **Renders OpenSCAD locais** para a unificação do gauntlet e os renames (Phoenix esquerda/direita/print; Paraglider montado/plano).
- **Suite de avaliação da tese** `test/thesis/` (REP/ROB/ACC), com as fixtures sincronizadas aos parâmetros atuais.

---

## 8. Síntese

| Modelo | Estado herdado | O que foi feito | Versões |
|---|---|---|---|
| **Flexy Beast** | escala fixa; charneira e gauntlet como meshes/STL | escala `(palm_breadth+5)/55`; dedos antropométricos (`REF_FINGER=37`); `flexy_joint()` paramétrico; gauntlet **partilhado com o Cyborg** por `wrist_circumference_mm` | v9.1, v13.1–13.2, v14.34, v14.70 |
| **Cyborg Beast** | Chicago-screw; dedos de 1 alavanca; sem gauntlet paramétrico | wrapper antropométrico; split proximal/distal analítico (`*_base_length_mm`); gauntlet orgânico auto-assente por `wrist_circumference_mm`; polegar calibrado vs STLs | v14.32, v14.37, v14.40, v14.44 |
| **Paraglider Reborn** | palma congelada a 1.25 (`use`+hardcoded) | palma volta a escalar (`scale(overall_scale/1.25)`); dedos paramétricos por dedo (`REF_FINGER=57.6`); consolidação multi-componente | v7.x, v14.11, v14.17 |
| **UnLimbited Phoenix** | meshes fixas; só escala global; override furava o piso | comprimento por dedo via `stretch_shaft` (haste sem furos); clamp 100–160%; hardware STEP; montagem/toggles/cores | v14.3, v14.18, v14.36, v14.45–48 |
| **(transversal)** | matcher ancorava tudo em ANSUR I Male; IA forçava mão direita | matcher multilingue + fallback LLM; lateralidade UI-only role-based | v14.16, v14.19 |
| **(coerência)** | grupos e nomes divergentes entre modelos | ordem canónica de grupos; `LeftRight→mirrored`; `show_assembled→print_layout` | v14.72 |

**Conclusão.** Cada prótese ativa teve de ser reconstruída ou corrigida para responder à antropometria: umas em SCAD paramétrico próprio (Flexy, Cyborg), outras com uma camada paramétrica à volta de meshes fixas (Phoenix, palma do Paraglider). A ligação perfil→modelo é centralizada em `profileMapping.js` sobre nomes canónicos; o gauntlet foi unificado entre os dois modelos que partilham a palma; e a interface foi normalizada para uma experiência coerente entre modelos. Todo o percurso foi validado por simulações de sizing, provas dimensionais e renders.

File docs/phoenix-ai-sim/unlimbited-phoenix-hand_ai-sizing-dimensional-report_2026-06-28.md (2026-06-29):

# UnLimbited Phoenix Hand — Relatório de Dimensões: Dimensionamento por IA → Exportação STL

**Data:** 2026-06-28 · **Versão do código:** v14.17.0
**Modelo:** UnLimbited Phoenix Hand (`models/active/unlimbed_phoenix_hand/UnLimbitedPhoenix.scad`)

**Método:** idêntico aos testes do Flexy Beast e do Paraglider — simulação ponta-a-ponta
de um utilizador real em `http://localhost:3000/edit` (login → abrir o modelo → escrever
dados antropométricos → sugestão **real** da IA via `POST /api/ai/suggest`,
`claude-sonnet-4-6` → aplicar → **Exportar STL**), browser conduzido com
Playwright/Chromium. Três perfis de paciente + um **baseline** por omissão.

**Especificidades deste modelo (vs os outros dois):**
- **Modelo inteiro, sem peças** → exporta **um único STL**. Por omissão `part = "Palm"`,
  logo o ficheiro exportado é o **palm Phoenix** (`Phoenix_Thermo_Palm_2()`).
- **Um só parâmetro antropométrico:** `palm_breadth_mm`, **com range `[82:131]`**.
  A escala deriva como `HandPerc = palm_breadth_mm / 82 × 100`, **limitada a 100–160 %**.
- Existe um escape manual: `HandPerc_override` (`0` = automático; a caption/ajuda dizem
  **"100–160 define-a diretamente"**), mas o seu range declarado é **`[0:160]`**.

**Referência estática:** o source paramétrico upstream do Team UnLimbited,
`tests/UnLimbited_Arm_V2.2.scad` (`part = 5`, *Palm*), que **embebe a mesma malha**
`Phoenix_Thermo_Palm_2` que o nosso modelo. Renderizado a 100 % dá
**91.96 × 82.17 × 30.55 mm** — coincidente com as funções `Phoenix_Thermo_Palm_2_dim*()`
embebidas no ficheiro.

Dados de apoio: [`run-metadata.json`](run-metadata.json), [`measurements.json`](measurements.json).

> 🔑 **Dois achados:** (1) a integração reproduz a malha Phoenix original **com exatidão**
> (≤ 0.06 mm); (2) o modelo tinha **dois caminhos de escala com floors inconsistentes** — a
> IA contornou o limite de tamanho mínimo via `HandPerc_override`, e fê-lo **só para a
> criança** (não para a mulher). **Corrigido em v14.18.0** (ambos os caminhos agora
> limitados a 100–160%). Ver §5–§6.

---

## 1. O prompt e os dados de paciente

Mesmo template dos outros testes. Inputs escritos (a única variável por perfil):

| Perfil | Texto livre introduzido |
|---|---|
| **criança** | *Criança de 7 anos, mão pequena. Largura da palma (nó a nó) cerca de 62 mm, dedo médio cerca de 56 mm, polegar cerca de 48 mm.* |
| **mulher** | *Mulher adulta, 34 anos, 165 cm, constituição magra. Sem medidas exatas — estima valores plausíveis a partir de normas populacionais.* |
| **homem** | *Homem adulto, 45 anos, 188 cm, mãos grandes. Largura dos nós dos dedos cerca de 96 mm, dedo médio cerca de 86 mm.* |

Grounding: os três pedidos voltaram `grounded: true` (matcher corrigido em v14.16.0,
ver `ai_anthropometric_validation.md` §2.4). Como o modelo só expõe `palm_breadth_mm`,
o bloco de grounding ancora apenas essa medida.

---

## 2. O que a IA devolveu (parâmetros aplicados)

| Perfil | `palm_breadth_mm` (range 82–131) | `HandPerc_override` (0 / 100–160) | → HandPerc efetivo | Resposta crua da IA |
|---|---:|---:|---:|---|
| baseline | 82 | 0 | 100 % | *(defaults)* |
| **criança** | 82 | **76** | **76 %** | `{"palm_breadth_mm": 82, "HandPerc_override": 76}` |
| mulher | 82 | 0 | 100 % | `{"palm_breadth_mm": 82, "HandPerc_override": 0, "LeftRight": "Left"}` |
| homem | 96 | 0 | 117 % | `{"palm_breadth_mm": 96}` |

**Leitura:** a IA percebeu que `palm_breadth_mm` não desce abaixo de 82 (o range mínimo)
e, **só para a criança**, usou `HandPerc_override = 76` para forçar uma impressão mais
pequena — atingindo 76 %, **abaixo** do limite de 100 % que o modelo impõe pela via do
`palm_breadth_mm`. Para a **mulher** (estimada ~78 mm, também < 82) **não** usou o override:
deixou-a no floor de 100 % (= 82 mm). O homem (96 mm) escalou normalmente para 117 %.

---

## 3. Dimensões exportadas vs referência (exatidão da integração)

O nosso modelo aplica `scale([HandPerc/100, …]) Phoenix_Thermo_Palm_2()` — a **mesma**
malha do upstream. Logo o STL exportado deve ser a malha de referência × HandPerc/100.

| Perfil | HandPerc | Comp. (mm) | **Larg. (mm)** | Alt. (mm) | referência × HandPerc | Δ largura |
|---|---:|---:|---:|---:|---:|---:|
| baseline | 100 % | 91.96 | **82.17** | 30.55 | 82.17 | **0.000 mm** |
| criança | 76 % | 69.89 | **62.45** | 23.22 | 62.45 | **0.000 mm** |
| mulher | 100 % | 91.96 | **82.17** | 30.55 | 82.17 | **0.000 mm** |
| homem | 117 % | 107.67 | **96.19** | 35.77 | 96.13 | 0.060 mm |
| *referência upstream (100 %)* | — | 91.96 | 82.17 | 30.55 | — | — |

A integração é **fiel ao milésimo**: o palm exportado coincide com a malha Phoenix
original escalada. Mais: o **baseline** e a **mulher** (ambos 100 %) são **byte-a-byte
idênticos** (mesmo MD5) e iguais à referência upstream — o nosso modelo preserva
exatamente a geometria do Team UnLimbited.

---

## 4. Validação do floor de tamanho

O modelo foi desenhado para **não imprimir abaixo de 100 %** (≈ 82 mm de largura de palma):
a caption do `palm_breadth_mm` di-lo (`clamped to 100–160%`), o range do parâmetro começa
em 82, e a ajuda do modelo recomenda *"para mãos muito pequenas, escolher um modelo mais
pequeno como o Flexy Beast"*. Confirmado pela via `palm_breadth_mm`:

- **mulher** (~78 mm estimado, < 82) → floored a **100 % / 82.17 mm** (igual ao baseline).

Mas há um **segundo caminho de escala que não respeita esse floor** — ver §5.

---

## 5. 🐛→✅ Achado: `HandPerc_override` contornava o floor (corrigido v14.18.0)

`HandPerc_override` é honrado como `HandPerc = override > 0 ? override : auto`. O seu
**range declarado é `[0:160]`**, mas a caption/ajuda dizem que só **`0`** (automático) ou
**`100–160`** (escala direta) fazem sentido — a faixa **1–99 é uma zona-morta** que a
documentação desencoraja.

A IA escolheu **`HandPerc_override = 76`** (dentro de `[0:160]`, mas na zona-morta), e o
modelo escalou o palm a **76 %**, produzindo uma largura de **62.45 mm** — **abaixo do
mínimo de 100 % / 82 mm** que o autor do modelo marcou como o limite imprimível da malha
Phoenix. Ou seja, existem **dois caminhos de dimensionamento com floors inconsistentes**:

| Caminho | Floor | Resultado para a criança |
|---|---|---|
| `palm_breadth_mm` (range 82–131, clamp 100–160 %) | **100 %** (≈ 82 mm) | bloqueado a 82 mm |
| `HandPerc_override` (range 0–160) | **nenhum** (aceita 1–99) | **76 % → 62 mm** |

**Inconsistência da IA:** perante a mesma necessidade (mão < 82 mm), a IA usou o override na
**criança** mas não na **mulher**. Mesmo modelo, dois comportamentos.

**Correção aplicada (v14.18.0).** Em `UnLimbitedPhoenix.scad`, o ramo do override passa a
ter o **mesmo clamp** que a via automática, por isso **nenhum** caminho desce abaixo de
100 %:

```openscad
HandPerc = HandPerc_override > 0
    ? max(100, min(160, HandPerc_override))                       // antes: HandPerc_override (sem floor)
    : max(100, min(160, palm_breadth_mm / REF_PALM_BREADTH * 100));
```

Verificação (render local):

| `HandPerc_override` | HandPerc antes | HandPerc depois | largura palm depois |
|---:|---:|---:|---:|
| 76 (o valor da criança) | 76 % | **100 %** | **82.17 mm** *(era 62.45)* |
| 0 (auto) | 100 % | 100 % | 82.17 mm *(sem alteração)* |
| 130 (override válido) | 130 % | 130 % | 106.81 mm *(sem alteração)* |

A zona-morta 1–99 fica fixada a 100 %; os overrides válidos (100–160) continuam a passar.
Assim, mesmo que a IA volte a sugerir `HandPerc_override = 76` para a criança, a peça sai a
100 % (o mínimo suportado) em vez de 62 mm.

> Nota: nunca foi um bug de geometria (a malha escala perfeitamente) — era uma **lacuna de
> validação/UX** que deixava a IA (ou um utilizador) produzir uma peça fora das tolerâncias
> previstas pelo autor; agora fechada.

---

## 6. Conclusões

1. **Pipeline validado** para o 3.º e último modelo — agora um export de **modelo inteiro
   ficheiro único** (sem modal de peças), conduzido pelo mesmo driver de browser.
2. **Integração exata:** o palm exportado reproduz a malha Phoenix upstream escalada, com
   Δ ≤ 0.06 mm; baseline e mulher (100 %) são idênticos à referência ao byte.
3. **Grounding correto** (matcher v14.16.0) nos três perfis.
4. **Floor de tamanho confirmado pela via `palm_breadth_mm`** (mulher e qualquer valor < 82
   mm ficam a 100 %).
5. **🐛→✅ Lacuna de validação (corrigida v14.18.0):** `HandPerc_override` (range `[0:160]`)
   permitia valores 1–99 que **contornavam** esse floor; a IA usou `76` na criança → palm de
   62 mm, abaixo do mínimo suportado, e de forma **inconsistente** com a mulher. Corrigido:
   ambos os caminhos de escala ficam agora limitados a 100–160% (§5).
6. **Adequação clínica:** este modelo **não serve mãos pequenas** (o próprio autor remete
   para o Flexy Beast). Para os perfis criança/mulher deste estudo, o Flexy Beast ou o
   Paraglider são as escolhas corretas; o Phoenix brilha de 82 mm para cima.

### Ressalvas
- Referência = `tests/UnLimbited_Arm_V2.2.scad` (`part = 5`), que embebe a **mesma** malha
  do nosso modelo — por isso a comparação valida a *integração/escala*, não duas geometrias
  independentes.
- Export = `part = "Palm"` (omissão); o modelo também gera Box/Pins/Fingers/Gauntlet via o
  parâmetro `part`, não cobertos aqui.
- STL exportados no scratchpad da sessão (`…/scratchpad/out_ph/`); só os resumos JSON ficam
  versionados.

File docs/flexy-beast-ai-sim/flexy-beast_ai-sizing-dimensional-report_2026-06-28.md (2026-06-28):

# Flexy Beast — Relatório de Dimensões: Dimensionamento por IA → Exportação STL

**Data:** 2026-06-28 · **Versão do código:** v14.16.0 (re-corrido **após** a correção do grounding)
**Modelo:** Flexy Beast (`models/active/flexy_beast/flexy_beast.scad`)

**Método:** Simulação ponta-a-ponta de um utilizador real na app em
`http://localhost:3000/edit` — login → abrir o Flexy Beast → escrever os dados
antropométricos do paciente → sugestão **real** da IA (`POST /api/ai/suggest`,
provider `anthropic`, `claude-sonnet-4-6`) → aplicar → **Exportar STL**. O browser
foi conduzido com Playwright/Chromium, por isso cada render passa pelo caminho de
exportação de produção OpenSCAD-WASM (`print_layout=true`, toggles por peça,
assentamento na base) — não houve atalho por CLI.

Três perfis de paciente mais um **baseline** com os parâmetros por omissão. Para
cada configuração exportaram-se 7 peças imprimíveis, medidas com `trimesh` (caixa
envolvente, extensões ordenadas `Comp. ≥ Larg. ≥ Alt.`, em mm), comparadas
(a) baseline-vs-IA e (b) contra os STL estáticos do daprice em
`tests/flexy-beast-original/stl/` (fixos a **160 % da escala base do Cyborg
Beast**).

Dados de apoio: [`run-metadata.json`](run-metadata.json) (prompts + respostas cruas
da IA + parâmetros aplicados) e [`measurements.json`](measurements.json) (geometria
de cada peça).

> **Nota:** esta é a 2.ª corrida, depois de corrigir o matcher de grounding
> (v14.16.0). A 1.ª corrida revelou que o grounding ancorava os três casos no mesmo
> grupo **masculino** — ver §2 para o antes→depois.

---

## 1. O prompt e os dados de paciente

O cliente envia um único prompt em template por pedido (idêntico entre perfis,
exceto a linha de dados do paciente e os valores `current`). Texto completo em
`run-metadata.json → profiles[].full_prompt_sent` (8 020 caracteres); estrutura:

```
You are sizing a 3D-printed parametric prosthetic hand model ("Flexy Beast") for a patient.

Patient anthropometric data:
<<< texto livre do utilizador — ver tabela abaixo >>>

These are the model's adjustable parameters … [37 parâmetros: name/caption/min/max/current] …

Guidance:
- Anthropometric parameters are anatomical measurements in millimetres … palm_breadth_mm (~70-100mm),
  index/middle/ring/pinky_finger_length_mm (MCP crease to tip), thumb_length_mm, gauntlet_width_mm …
- If the data is qualitative … estimate plausible adult measurements from population norms;
  women typically run smaller than men.
- Keep proportions realistic … Only suggest values for parameters listed above … stay within min/max.
- Leave hardware/visibility/color parameters at their current values unless the patient data implies a change.

Respond with ONLY a valid JSON object mapping parameter names to suggested values. No prose, no markdown.
```

Ao prompt é anexado, do lado do servidor, um **bloco de grounding** populacional
(ver §2). Dados de paciente escritos (a única variável por perfil):

| Perfil | Texto livre introduzido |
|---|---|
| **criança** | *Criança de 7 anos, mão pequena. Largura da palma (nó a nó) cerca de 62 mm, dedo médio cerca de 56 mm, polegar cerca de 48 mm.* |
| **mulher** | *Mulher adulta, 34 anos, 165 cm, constituição magra. Sem medidas exatas — estima valores plausíveis a partir de normas populacionais.* |
| **homem** | *Homem adulto, 45 anos, 188 cm, mãos grandes. Largura dos nós dos dedos cerca de 96 mm, dedo médio cerca de 86 mm.* |

---

## 2. Grounding antropométrico — antes → depois da correção

O servidor procura na tabela `anthropometric_profiles` (100 perfis populacionais)
o grupo mais próximo do paciente e anexa as suas médias medidas ao prompt como
âncora (precedência: medidas explícitas do paciente > médias populacionais).

**Antes (v14.15.0):** o matcher ancorava os **três** casos no mesmo grupo
masculino. Causa: o token de género masculino `'m,'` estava contido nas unidades
`"mm,"`/`"cm,"`, logo qualquer texto com medidas era lido como **masculino**; e o
parsing de género/idade era só em inglês (ignorava "Mulher", "Criança", "7 anos").

**Depois (v14.16.0):** match correto por género + escalão etário + proximidade de
idade. Reproduzido com os mesmos textos:

| Perfil | Grupo escolhido **antes** | Grupo escolhido **depois** | Como |
|---|---|---|---|
| criança | ANSUR I **Male** 50th (palma 90.3 mm) | **Dutch children KIMA, age 7** | idade 7 (det.) → escalão *child* + proximidade |
| mulher | ANSUR I **Male** 50th | **ANSUR I Female 50th + Hand Survey** | "Mulher"→female, "34 anos"→adult |
| homem | ANSUR I Male 50th | **ANSUR I Male 50th + Hand Survey** | "Homem"→male, "45 anos"→adult |

A DB tinha sempre os perfis certos (39 femininos, 37 masculinos, idades 2→80+,
incluindo `ANSUR I Female 50th` e `Dutch children … age 7`); o problema era o
matcher, agora resolvido. Detalhe técnico da correção em §7.

---

## 3. O que a IA devolveu (parâmetros aplicados)

| Parâmetro | omissão | criança | mulher | homem |
|---|---:|---:|---:|---:|
| palm_breadth_mm | 83 | **62** | **77** | **96** |
| middle_finger_length_mm | 72 | 56 | 77 | 86 |
| index_finger_length_mm | 68 | 52 | 70 | 78 |
| ring_finger_length_mm | 68 | 52 | 73 | 82 |
| pinky_finger_length_mm | 55 | 40 | 59 | 67 |
| thumb_length_mm | 65 | 48 | 63 | 73 |
| gauntlet_width_mm | 60 | 47 | 57 | 60 |
| gauntlet_length_mm | 108 | 80 | 100 | 108 |
| joint_dia | 7 | **5** | 6 | 7 |
| joint_thick | 4 | **2** | 3 | 4 |
| wrist_pin_dia | 7 | **5** | 7 | 7 |

**Observações**
- Medidas quantitativas (criança, homem) respeitadas quase à letra (palma 62/96).
- A **mulher** está agora ancorada no dataset **feminino** ANSUR I (antes era
  masculino): a IA produziu uma mão de adulta franzina coerente (palma 77, médio
  77, polegar 63) e reduziu o gauntlet (57×100) — algo que na 1.ª corrida, com
  âncora masculina, não acontecia.
- Hardware segue as captions: criança com `joint_dia 5`, `joint_thick 2`,
  `wrist_pin_dia 5` (as captions dizem *"reduce to 5/2 mm for children's hands"*);
  intermédio na mulher; defaults no homem.

---

## 4. Dimensões dos STL exportados — baseline vs IA (extensão mais longa, mm)

Cada valor medido a partir do STL realmente exportado. `Δ` vs o baseline por omissão.

| Peça | baseline | criança (Δ / %) | mulher (Δ / %) | homem (Δ / %) |
|---|---:|---:|---:|---:|
| palm | 124.20 | 94.56 (−29.6 / −23.9 %) | 115.73 (−8.5 / −6.8 %) | 142.55 (+18.4 / +14.8 %) |
| index_base | 43.16 | 32.98 (−10.2 / −23.6 %) | 43.80 (+0.6 / +1.5 %) | 49.51 (+6.4 / +14.7 %) |
| index_tip | 62.77 | 47.78 (−15.0 / −23.9 %) | 61.51 (−1.3 / −2.0 %) | 72.10 (+9.3 / +14.9 %) |
| middle_base | 45.32 | 35.14 (−10.2 / −22.5 %) | 47.59 (+2.3 / +5.0 %) | 53.83 (+8.5 / +18.8 %) |
| middle_tip | 64.61 | 49.62 (−15.0 / −23.2 %) | 64.73 (+0.1 / +0.2 %) | 75.78 (+11.2 / +17.3 %) |
| thumb_base | 41.54 | 30.82 (−10.7 / −25.8 %) | 40.02 (−1.5 / −3.7 %) | 46.80 (+5.3 / +12.7 %) |
| thumb_tip | 35.20 | 26.80 (−8.4 / −23.9 %) | 32.80 (−2.4 / −6.8 %) | 39.46 (+4.3 / +12.1 %) |

**A geometria acompanha linearmente os parâmetros.** Comprimento da palma vs
`palm_breadth_mm`:

| config | palm_breadth_mm | comp. palma (mm) | comp. / breadth |
|---|---:|---:|---:|
| criança | 62 | 94.56 | 1.525 |
| mulher | 77 | 115.73 | 1.503 |
| baseline | 83 | 124.20 | 1.496 |
| homem | 96 | 142.55 | 1.485 |

Nota: as **pontas** dos dedos exportam como cascas abertas (`watertight: false`, sem
volume fechado) porque `finger_pads=true` esvazia-as para moldar as almofadas de
silicone — esperado.

---

## 5. Comparação dimensional peça-a-peça (completa)

Um bloco por peça: caixa envolvente completa de cada config (Comp.×Larg.×Alt. +
volume), variação vs baseline, e a linha da **referência estática daprice (160 %)**
em linha.

> Mapeamento estático: `palm → palm.stl`; peças `*_base` → `finger_base.stl`;
> `index_tip`/`middle_tip` → `finger_tip.stl`; `thumb_tip → thumb_tip.stl`.

**palm**

| Config | Comp. (mm) | Larg. (mm) | Alt. (mm) | vol (cm³) | ΔComp. vs baseline |
|---|---:|---:|---:|---:|---:|
| baseline | 124.20 | 102.16 | 47.35 | 104.39 | — |
| criança | 94.56 | 77.78 | 36.05 | 47.11 | -29.64 (-23.9%) |
| mulher | 115.73 | 95.19 | 44.12 | 85.27 | -8.47 (-6.8%) |
| homem | 142.55 | 117.25 | 54.34 | 158.53 | +18.35 (+14.8%) |
| *estático palm (160%)* | 116.44 | 95.78 | 47.35 | — | — |

**index_base**

| Config | Comp. (mm) | Larg. (mm) | Alt. (mm) | vol (cm³) | ΔComp. vs baseline |
|---|---:|---:|---:|---:|---:|
| baseline | 43.16 | 19.02 | 18.84 | 9.03 | — |
| criança | 32.98 | 14.48 | 14.35 | 4.13 | -10.18 (-23.6%) |
| mulher | 43.80 | 17.72 | 17.56 | 8.49 | +0.64 (+1.5%) |
| homem | 49.51 | 21.83 | 21.63 | 14.51 | +6.35 (+14.7%) |
| *estático finger_base (160%)* | 40.50 | 18.84 | 17.83 | — | — |

**index_tip**

| Config | Comp. (mm) | Larg. (mm) | Alt. (mm) | vol (cm³) | ΔComp. vs baseline |
|---|---:|---:|---:|---:|---:|
| baseline | 62.77 | 24.76 | 19.02 | — | — |
| criança | 47.78 | 22.04 | 14.48 | — | -14.99 (-23.9%) |
| mulher | 61.51 | 25.46 | 17.72 | — | -1.26 (-2.0%) |
| homem | 72.10 | 23.25 | 21.83 | — | +9.33 (+14.9%) |
| *estático finger_tip (160%)* | 58.56 | 22.12 | 17.83 | 11.27 | — |

**middle_base**

| Config | Comp. (mm) | Larg. (mm) | Alt. (mm) | vol (cm³) | ΔComp. vs baseline |
|---|---:|---:|---:|---:|---:|
| baseline | 45.32 | 19.02 | 18.84 | 9.74 | — |
| criança | 35.14 | 14.48 | 14.35 | 4.53 | -10.18 (-22.5%) |
| mulher | 47.59 | 17.72 | 17.56 | 9.56 | +2.27 (+5.0%) |
| homem | 53.83 | 21.83 | 21.63 | 16.38 | +8.51 (+18.8%) |
| *estático finger_base (160%)* | 40.50 | 18.84 | 17.83 | — | — |

**middle_tip**

| Config | Comp. (mm) | Larg. (mm) | Alt. (mm) | vol (cm³) | ΔComp. vs baseline |
|---|---:|---:|---:|---:|---:|
| baseline | 64.61 | 24.76 | 19.02 | — | — |
| criança | 49.62 | 22.04 | 14.48 | — | -14.99 (-23.2%) |
| mulher | 64.73 | 25.46 | 17.72 | — | +0.12 (+0.2%) |
| homem | 75.78 | 23.25 | 21.83 | — | +11.17 (+17.3%) |
| *estático finger_tip (160%)* | 58.56 | 22.12 | 17.83 | 11.27 | — |

**thumb_base**

| Config | Comp. (mm) | Larg. (mm) | Alt. (mm) | vol (cm³) | ΔComp. vs baseline |
|---|---:|---:|---:|---:|---:|
| baseline | 41.54 | 19.02 | 18.84 | 8.50 | — |
| criança | 30.82 | 14.48 | 14.35 | 3.72 | -10.72 (-25.8%) |
| mulher | 40.02 | 17.72 | 17.56 | 7.41 | -1.52 (-3.7%) |
| homem | 46.80 | 21.83 | 21.63 | 13.34 | +5.26 (+12.7%) |
| *estático finger_base (160%)* | 40.50 | 18.84 | 17.83 | — | — |

**thumb_tip**

| Config | Comp. (mm) | Larg. (mm) | Alt. (mm) | vol (cm³) | ΔComp. vs baseline |
|---|---:|---:|---:|---:|---:|
| baseline | 35.20 | 19.02 | 18.63 | — | — |
| criança | 26.80 | 14.48 | 14.35 | — | -8.40 (-23.9%) |
| mulher | 32.80 | 17.72 | 17.56 | — | -2.40 (-6.8%) |
| homem | 39.46 | 21.83 | 16.24 | — | +4.26 (+12.1%) |
| *estático thumb_tip (160%)* | 33.95 | 18.43 | 17.20 | 3.91 | — |

---

## 6. Comparação com a referência estática daprice

Os STL de demo estão fixos a **160 % da escala base do Cyborg Beast** (malha mais
antiga; é uma verificação de *envelope/tamanho*, não um diff ao nível do vértice).

| Peça estática | estático Comp.×Larg.×Alt. (mm) | config mais próxima | a nossa Comp.×Larg.×Alt. (mm) |
|---|---|---|---|
| palm.stl | 116.44 × 95.78 × 47.35 | **mulher** | 115.73 × 95.19 × 44.12 |
| finger_base.stl | 40.50 × 18.84 × 17.83 | mulher (index_base) | 43.80 × 17.72 × 17.56 |
| finger_tip.stl | 58.56 × 22.12 × 17.83 | mulher (index_tip) | 61.51 × 25.46 × 17.72 |
| thumb_tip.stl | 33.95 × 18.43 × 17.20 | mulher (thumb_tip) | 32.80 × 17.72 × 17.56 |

**Conclusão:** a demo daprice 160 % corresponde quase exatamente ao
dimensionamento de **mulher adulta franzina** deste modelo (palma 116.4 vs 115.7
mm, < 1 % no eixo mais longo). O default do repo (83 mm → 124 mm) é ~6–7 % maior, e
o homem ~22 % maior. O rebuild paramétrico reproduz o envelope da referência a
poucos mm quando dimensionado para a mesma mão.

---

## 7. A correção (o que mudou no código)

**Opção 1 — matcher determinístico** (`server/services/profileMapping.js`):
- Tokens de género com **fronteira de palavra Unicode** (já não substring) → as
  unidades `"mm,"`/`"cm,"` deixam de ser lidas como masculino.
- Dicionário **multilingue** (EN/PT/ES) de género e de escalão etário.
- `extractAge` entende "anos"/"años"; e as alturas/larguras ("188 cm") não são lidas
  como idade.
- `age_group` numérico da DB ("7", "18-30", "80+", "Adult (Military, 17–40)") é
  reduzido a um escalão (child/adult/elderly) **com proximidade numérica de idade**
  → um 7 anos cai no dataset de crianças de 7 anos.

**Opção 2 — extração estruturada via LLM** (`aiService.extractPatientAttributes`,
`claude-haiku-4-5`): para texto livre/qualitativo, extrai `{gender, age}` em JSON e
alimenta o matcher. Corre **só quando** o parser determinístico fica incompleto
(eficiente) e degrada graciosamente para o parser em caso de erro/sem chave. Ex.
verificado: *"retired schoolteacher, mid-seventies"* → o parser falha → o LLM infere
`age 75`. (Subsome a ideia de "traduzir para inglês", sem chamada extra na maioria
dos casos.)

**Testes:** `test/profileMapping.test.js` (`npm run test:unit`, 10/10 a passar) —
cobre a regressão das unidades-como-masculino, o parsing multilingue, o bucketing de
idade e o override por hints.

Nesta corrida, os 3 perfis tinham género+idade explícitos, por isso o match correto
veio do parser determinístico (Opção 1); a Opção 2 é o reforço para descrições
ambíguas.

---

## 8. Conclusões

1. **Pipeline de produção validado ponta-a-ponta** pela UI real (login, IA
   autenticada, exportação STL por peça via OpenSCAD-WASM).
2. **Grounding corrigido:** a mulher passou a ancorar num dataset **feminino** e a
   criança num dataset de **crianças de 7 anos** (antes ambas em ANSUR I Male). A
   geometria exportada reflete-o (mulher agora ~6.8 % abaixo do baseline na palma,
   com dedos coerentes com a âncora feminina).
3. **Geometria fiel aos parâmetros:** comprimentos escalam linearmente com as
   entradas (comp. palma / breadth ≈ 1.49–1.52 numa gama 62→96 mm).
4. **Fidelidade ao original:** dimensionado para a mesma mão, o Flexy Beast
   paramétrico reproduz o envelope da demo daprice 160 % a < 1 % na palma; a única
   diferença estrutural são as pontas dos dedos intencionalmente ocas.
5. **Melhoria dos dados antropométricos entregue (v14.16.0):** Opção 1 (matcher
   determinístico) + Opção 2 (extração LLM), com testes unitários. Os 39 perfis
   femininos e os de criança da DB deixaram de ficar por usar.

### Ressalvas
- Referência estática = escala fixa de 160 % e malha antiga → §6 é envelope/tamanho.
- Extensões ordenadas (`Comp.≥Larg.≥Alt.`); secções das pontas refletem a orientação
  de impressão.
- Os pacotes STL (4 ZIP, 7 peças) estão no scratchpad da sessão (`…/scratchpad/out_v2/`);
  aqui só ficam versionados os resumos JSON. Diz se queres os STL no repositório.

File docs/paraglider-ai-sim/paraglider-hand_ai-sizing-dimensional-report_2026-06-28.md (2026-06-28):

# Paraglider · Hand — Relatório de Dimensões: Dimensionamento por IA → Exportação STL

**Data:** 2026-06-28 · **Versão do código:** v14.16.0
**Modelo:** Paraglider · Hand (`models/active/paraglider_hand/paraglider_hand.scad`),
defaults `component = Hand`, `palm_style = Reborn`.

**Método:** idêntico ao teste do Flexy Beast — simulação ponta-a-ponta de um
utilizador real em `http://localhost:3000/edit` (login → abrir Paraglider → escrever
dados antropométricos → sugestão **real** da IA via `POST /api/ai/suggest`,
`claude-sonnet-4-6` → aplicar → **Exportar STL**), browser conduzido com
Playwright/Chromium. Cada render passa pelo caminho de produção OpenSCAD-WASM, com as
9 dependências do modelo (`.scad` + 2 `.stl`) montadas automaticamente pelo
`loadModel`. Três perfis de paciente + um **baseline** por omissão; 6 peças
exportadas por config (palm, index, middle, ring, pinky, thumb), medidas com
`trimesh`.

**Referência estática:** os meshes-fonte do **Flexible Flyer** em
`tests/flexible-flyer-master/.../files/` (`palm_left_v2_nobox.stl` — o palm Reborn —
e `Unlimbited_v3_palm_left_f360.stl`).

Dados de apoio: [`run-metadata.json`](run-metadata.json) e
[`measurements.json`](measurements.json).

> ⚠️ **Principal achado (CORRIGIDO em v14.17.0):** o **palm não escalava** com os
> dados antropométricos — ficava congelado no tamanho médio (breadth 83) para
> qualquer paciente (os dedos escalavam bem). Era um bug do modelo, não do pipeline.
> Foi corrigido e re-testado: o palm passa a escalar (criança 84.9 / homem 131.5 mm).
> Ver §6 para a causa-raiz, a correção e a verificação antes→depois.

---

## 1. O prompt e os dados de paciente

Mesmo template do teste do Flexy (texto completo em
`run-metadata.json → profiles[].full_prompt_sent`). O Paraglider expõe um conjunto
antropométrico **mais rico** que o Flexy — inclui `palm_length_mm` e
`palm_thickness_mm`. Inputs escritos (a única variável por perfil):

| Perfil | Texto livre introduzido |
|---|---|
| **criança** | *Criança de 7 anos, mão pequena. Largura da palma (nó a nó) cerca de 62 mm, dedo médio cerca de 56 mm, polegar cerca de 48 mm.* |
| **mulher** | *Mulher adulta, 34 anos, 165 cm, constituição magra. Sem medidas exatas — estima valores plausíveis a partir de normas populacionais.* |
| **homem** | *Homem adulto, 45 anos, 188 cm, mãos grandes. Largura dos nós dos dedos cerca de 96 mm, dedo médio cerca de 86 mm.* |

---

## 2. Grounding antropométrico (já com a correção v14.16.0)

O matcher corrigido escolheu o grupo populacional certo em cada caso (precedência:
medidas do paciente > médias populacionais):

| Perfil | género/idade detetados | grupo escolhido | médias mapeadas (palma breadth / length, mm) |
|---|---|---|---|
| criança | —/7 | **Dutch children KIMA, age 7** | 64 / 138* |
| mulher | female/34 | **ANSUR I Female 50th + Hand Survey** | 79.3 / 104 |
| homem | male/45 | **ANSUR I Male 50th + Hand Survey** | 90.3 / 113.8 |

\* O dataset de crianças trazia um `palm_length` de 138 mm (claramente errado para
7 anos). A IA **ignorou-o** corretamente (produziu `palm_length 60`), porque o
contexto "criança, mão pequena" + as medidas explícitas pequenas têm precedência —
bom exemplo de robustez. Para a **mulher**, a média feminina mapeada `palm_length
104` explica diretamente o valor sugerido (103 mm).

---

## 3. O que a IA devolveu (parâmetros aplicados)

| Parâmetro | omissão | criança | mulher | homem |
|---|---:|---:|---:|---:|
| palm_breadth_mm | 83 | **62** | **78** | **96** |
| palm_length_mm | 95 | 60 | 103 | 120 |
| palm_thickness_mm | 32 | 20 | 26 | 32 |
| middle_finger_length_mm | 72 | 56 | 78 | 86 |
| index_finger_length_mm | 68 | 51 | 71 | 79 |
| ring_finger_length_mm | 68 | 51 | 73 | 82 |
| pinky_finger_length_mm | 55 | 40 | 60 | 67 |
| thumb_length_mm | 65 | 48 | 64 | 74 |

A IA produziu valores antropometricamente coerentes para os **8** campos. Pós-correção
(§6), `palm_breadth_mm` passa a escalar o palm (e os `*_finger_length_mm` escalam os
dedos). Nota: `palm_length_mm` e `palm_thickness_mm` continuam a ser **só para
alinhamento com perfis/IA** — o palm escala uniformemente a partir de `palm_breadth_mm`
(é assim por design: os furos dos pinos têm de ficar circulares, logo o palm não pode
ser escalado não-uniformemente), tal como documentado nas captions do modelo.

---

## 4. Dimensões dos STL exportados (extensão mais longa, mm) — após a correção

| Peça | baseline | criança (Δ%) | mulher (Δ%) | homem (Δ%) |
|---|---:|---:|---:|---:|
| **palm** | 113.70 | **84.94 (−25.3 %)** | **105.49 (−7.2 %)** | **131.51 (+15.7 %)** |
| index | 93.08 | 82.31 (−11.6 %) | 94.98 (+2.0 %) | 100.05 (+7.5 %) |
| middle | 95.62 | 85.48 (−10.6 %) | 99.42 (+4.0 %) | 104.49 (+9.3 %) |
| ring | 90.72 | 80.54 (−11.2 %) | 93.72 (+3.3 %) | 99.11 (+9.2 %) |
| pinky | 82.94 | 73.95 (−10.8 %) | 85.93 (+3.6 %) | 90.12 (+8.7 %) |
| thumb | 89.87 | 81.01 (−9.9 %) | 93.19 (+3.7 %) | 97.62 (+8.6 %) |

Pós-correção, o palm escala uniformemente: comp./breadth = **1.370 constante** nas 4
configs (113.70/83 = 84.94/62 = 105.49/77 = 131.51/96). Antes da correção, o palm
era byte-a-byte idêntico (mesmo MD5) nas 4 — ver §6. Os valores das peças de dedo são
os mesmos de antes (a correção só toca no palm).

> **Nota de método (dedos):** no print-layout do Paraglider, cada peça de dedo
> exportada agrupa a **falange + a ponta** com um espaçamento fixo de 50 mm, por isso
> a *Comp.* da bbox mistura geometria que escala com um gap que não escala — varia
> menos do que o parâmetro. O indicador limpo é a **secção transversal** (largura),
> que escala **exatamente** com o parâmetro do dedo (ver §5).

---

## 5. Os dedos escalam corretamente (verificação pela secção)

A largura da bbox de cada dedo segue o respetivo `*_finger_length_mm` ao milésimo.
Exemplo do indicador (param `index_finger_length_mm`, escala = length / 57.6):

| config | index_finger_length_mm | escala param (vs base) | Larg. index (mm) | escala Larg. (vs base) |
|---|---:|---:|---:|---:|
| baseline | 68 | 1.000 | 19.69 | 1.000 |
| criança | 51 | 0.750 | 14.77 | 0.750 |
| mulher | 71 | 1.044 | 20.56 | 1.044 |
| homem | 79 | 1.162 | 22.87 | 1.162 |

As duas últimas colunas são idênticas → os dedos escalam uniformemente e
proporcionalmente. O mesmo se verifica para middle/ring/pinky/thumb (tabela completa
em §7 e em `measurements.json`).

---

## 6. 🐛→✅ Bug do palm: encontrado e corrigido (v14.17.0)

**Sintoma (antes):** o palm exportado media **113.70 × 100.80 × 38.19 mm em todas as
configurações** (criança breadth 62, mulher 78, homem 96 — todos iguais; STL
byte-a-byte idêntico). Confirmado também por render local com OpenSCAD CLI (não era
artefacto do export do browser): o palm a `palm_breadth_mm=62` era idêntico ao de `=96`.

**Causa-raiz:** em `paraglider_palm_left.scad`, **linha 4: `overall_scale = 1.25;`**
(default hardcoded). O ficheiro principal calcula
`overall_scale = palm_breadth_mm / 66.4` (linha 107) mas puxa o palm Reborn com
**`use <paraglider_palm_left.scad>`** (linha 205). `use` é de escopo **léxico**, por
isso o módulo `scaled_palm()` resolve `overall_scale` no escopo do **seu próprio
ficheiro** (1.25) e ignora o valor antropométrico do principal. Os **dedos** escapam
porque recebem a escala como **argumento** (`_finger_phalanx(index_scale)`); o palm
não recebia nada. (O `palm_style="UnlimbitedV3"` **já estava correto**: `pg_v3palm.scad`
entra por **`include`**, logo o seu `V3_overall_scale` resolve para o valor do
principal — verificado: V3 escala 62→85.9, 96→133.0 mm.)

**Prova numérica (antes):** palm 113.70 mm = palm Reborn de origem (90.96 mm) × 1.25
— exatamente o tamanho de breadth 83, congelado.

**Impacto clínico:** uma criança configurada a 62 mm recebia dedos de criança montados
num **palm de adulto** (breadth 83) — proporções partidas, peça impossível de montar.

**Correção aplicada** (`paraglider_hand.scad`): como `scaled_palm()` já cozinha a
escala 1.25 (= 83/66.4), reaplica-se a escala antropométrica em falta no ponto de
chamada do Reborn:
```
else scale(overall_scale / 1.25) scaled_palm();   // 1.25 × overall_scale/1.25 = palm_breadth_mm/66.4
```
Isolado a uma linha do ficheiro principal (não toca na biblioteca `use`d, sem risco de
colisão de variáveis); o caminho V3 fica intacto.

**Verificação (depois):** o palm Reborn passa a escalar, com **comp./breadth = 1.370
constante** e **sem regressão** no tamanho de referência (breadth 83 inalterado):

| breadth (config) | palm comp. antes | palm comp. depois |
|---|---:|---:|
| 62 (criança) | 113.70 | **84.94** |
| 77 (mulher) | 113.70 | **105.49** |
| 83 (baseline) | 113.70 | 113.70 *(igual — sem regressão)* |
| 96 (homem) | 113.70 | **131.51** |

Confirmado tanto por render local OpenSCAD como pela re-corrida completa do fluxo no
browser (login → IA → export). Ressalva: a correção escala o palm uniformemente
(incluindo os canais de cordel/elástico), em linha com o comportamento dos dedos — se
se quiser manter os canais a tamanho absoluto fixo, é um refinamento separado.

---

## 7. Comparação dimensional peça-a-peça (completa)

Caixa envolvente de cada config + referência estática (apenas o palm tem mesh-fonte;
os dedos do Flexible Flyer são gerados por `fingerator.scad`, sem STL estático).

**palm**

| Config | Comp. (mm) | Larg. (mm) | Alt. (mm) | ΔComp. vs baseline |
|---|---:|---:|---:|---:|
| baseline | 113.70 | 100.80 | 38.19 | — |
| criança | 84.94 | 75.30 | 28.53 | −28.76 (−25.3%) |
| mulher | 105.49 | 93.52 | 35.43 | −8.21 (−7.2%) |
| homem | 131.51 | 116.59 | 44.17 | +17.81 (+15.7%) |
| *estático Reborn palm (fonte)* | 90.96 | 80.64 | 30.55 | — |
| *estático Unlimbited v3 palm (fonte)* | 92.00 | 82.86 | 30.64 | — |

**index**

| Config | Comp. (mm) | Larg. (mm) | Alt. (mm) | ΔLarg. vs baseline |
|---|---:|---:|---:|---:|
| baseline | 93.08 | 19.69 | 14.49 | — |
| criança | 82.31 | 14.77 | 10.87 | −25.0% |
| mulher | 94.98 | 20.56 | 15.13 | +4.4% |
| homem | 100.05 | 22.87 | 16.83 | +16.2% |

**middle**

| Config | Comp. (mm) | Larg. (mm) | Alt. (mm) | ΔLarg. vs baseline |
|---|---:|---:|---:|---:|
| baseline | 95.62 | 20.85 | 15.34 | — |
| criança | 85.48 | 16.21 | 11.93 | −22.3% |
| mulher | 99.42 | 22.58 | 16.62 | +8.3% |
| homem | 104.49 | 24.90 | 18.33 | +19.4% |

**ring**

| Config | Comp. (mm) | Larg. (mm) | Alt. (mm) | ΔLarg. vs baseline |
|---|---:|---:|---:|---:|
| baseline | 90.72 | 19.69 | 14.49 | — |
| criança | 80.54 | 14.77 | 10.87 | −25.0% |
| mulher | 93.72 | 21.14 | 15.56 | +7.4% |
| homem | 99.11 | 23.74 | 17.47 | +20.6% |

**pinky**

| Config | Comp. (mm) | Larg. (mm) | Alt. (mm) | ΔLarg. vs baseline |
|---|---:|---:|---:|---:|
| baseline | 82.94 | 15.92 | 11.72 | — |
| criança | 73.95 | 11.58 | 8.52 | −27.3% |
| mulher | 85.93 | 17.37 | 12.78 | +9.1% |
| homem | 90.12 | 19.40 | 14.28 | +21.9% |

**thumb**

| Config | Comp. (mm) | Larg. (mm) | Alt. (mm) | vol (cm³) | ΔLarg. vs baseline |
|---|---:|---:|---:|---:|---:|
| baseline | 89.87 | 20.85 | 16.74 | 9.93 | — |
| criança | 81.01 | 16.21 | 13.02 | 4.61 | −22.3% |
| mulher | 93.19 | 22.58 | 18.13 | 12.67 | +8.3% |
| homem | 97.62 | 24.90 | 19.99 | 17.05 | +19.4% |

---

## 8. Comparação com a referência estática (Flexible Flyer)

O mesh Reborn de origem (`palm_left_v2_nobox.stl`) está à escala 1.0 (breadth ≈ 66.4
mm, comp. 90.96 mm). Pós-correção, o nosso palm escala em torno dela, em vez do
tamanho único congelado de antes:

| config (breadth) | o nosso palm comp. (mm) | vs Reborn-fonte (90.96) |
|---|---:|---:|
| criança (62) | 84.94 | −6.6 % |
| baseline (83) | 113.70 | +25.0 % |
| mulher (77) | 105.49 | +16.0 % |
| homem (96) | 131.51 | +44.6 % |

A referência confirma a correção: o palm da criança (breadth 62) aproxima-se do mesh
Reborn de origem (que é ~breadth 66), e cada paciente recebe um palm proporcional à
sua mão — uma família de tamanhos, não um valor fixo. (Antes da correção, todas as
linhas seriam 113.70 / +25.0 %.)

---

## 9. Conclusões

1. **Pipeline de produção validado** para um 2.º modelo, mais complexo (import de
   STL + 9 dependências montadas pela app, manifold).
2. **Grounding corrigido a funcionar** também aqui: género/idade certos, datasets
   femininos/criança usados, dataset com `palm_length` errado ignorado pela IA.
3. **Sugestão de parâmetros da IA correta** nos 8 campos antropométricos.
4. **Dedos escalam fielmente** com os parâmetros (secção transversal = razão do
   parâmetro, ao milésimo).
5. **🐛→✅ Bug encontrado e corrigido (v14.17.0):** o **palm Reborn não escalava** com
   `palm_breadth_mm` — congelado em scale 1.25 — por `use <paraglider_palm_left.scad>`
   + `overall_scale=1.25` hardcoded no módulo (§6). Crítico clinicamente (criança
   recebia palm de adulto). Corrigido com uma linha (`scale(overall_scale/1.25)`) e
   re-testado: o palm passa a escalar (criança 84.9 / homem 131.5 mm), sem regressão
   no tamanho de referência. O caminho UnlimbitedV3 já estava correto.

### Ressalvas
- Referência estática = mesh-fonte do Flexible Flyer; só o palm tem STL de origem
  (dedos são paramétricos via `fingerator.scad`).
- Para os dedos, a *Comp.* da bbox inclui o gap fixo de 50 mm do print-layout
  (falange+ponta na mesma peça); usar a **largura** como indicador de escala (§5).
- Pacotes STL (4 ZIP × 6 peças) no scratchpad da sessão (`…/scratchpad/out_pg/`); só
  os resumos JSON ficam versionados.

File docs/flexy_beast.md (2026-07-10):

# Flexy Beast — Integration Notes

This document explains how the Flexy Beast prosthetic hand design was integrated into the AI Parametric Prosthetic Hand Generator platform. It covers the source design, what was built, the anthropometric parameter mapping, and the conversion decisions made.

---

## 1. Source Design

The **Flexy Beast** is a wrist-powered prosthetic hand for the [e-NABLE Project](http://enablingthefuture.org), designed by [daprice](https://github.com/daprice/Flexy-Beast) and released under CC BY-SA 4.0. It is a mashup of the [Parametric Cyborg Beast](http://www.thingiverse.com/thing:320173) (MakerBlock) and the [Flexy Hand](http://www.thingiverse.com/thing:380665) (Steve Wood / Gyrobot).

Its key contribution over the Cyborg Beast is replacing Chicago screws and elastics with **flexible joints** (Filaflex inserts or cast silicone) that snap into slots cut into the knuckle blocks. This makes the hand lighter, cheaper, and easier to assemble. Optional silicone finger-pad hollows in the fingertips improve grip.

### Source files

The upstream [Flexy Beast repository](https://www.thingiverse.com/thing:380665) (by daprice) has the following structure:

```
src/
  config.scad                   — sizing variables and scale factors
  assembly.scad                 — hand layout (calls top-level modules)
  parts/
    palm.scad                   — palm body, knuckle blocks, wrist hinges
    thumb_tip.scad              — distal thumb phalanx
    finger_tip_mold.scad        — mold for casting silicone finger pads
    util/
      finger_base.scad          — proximal finger segment module
      finger_mid.scad           — middle finger segment module
      finger_tip.scad           — distal finger segment modules
      thermoform.scad           — thermoformable mesh for palm interior
stl/                            — pre-rendered STL exports (not used)
```

All geometry in `src/` is native OpenSCAD — no STL imports anywhere in the source tree.

---

## 2. Approach: Self-Contained Single File

The upstream source is split across seven SCAD files. Each non-assembly file begins with `include <path/to/config.scad>` to pull in the sizing variables, and each file also has a top-level geometry call (so it renders as a stand-alone part in OpenSCAD's customizer). This structure creates two problems for integration:

1. **Include path collision.** The WASM virtual filesystem is flat — all files end up at the root with no subdirectory structure. The relative `include <../../config.scad>` paths inside `src/parts/util/` would be unresolvable.

2. **Top-level calls.** Each source file renders geometry at the top level, so `use<>`ing them from a master file would silently inherit unwanted top-level renders.

Rather than patching all include paths and stripping all top-level calls across seven files, all geometry was consolidated into a **single self-contained file**:

```
models/active/flexy_beast/flexy_beast.scad
```

This file has no external dependencies and requires no entries in the `"dependencies"` array of `models-config.json`.

---

## 3. What Was Built

`flexy_beast.scad` inlines all module definitions from the upstream source files in the following order:

| Upstream file | Modules inlined |
|---|---|
| `assembly.scad` | `handlayout`, `fingerlayout`, `thumbmid` |
| `parts/palm.scad` | `cyborgbeastpalm`, `cyborgthumbsolid`, `cyborgbeast07palminsidespace`, `hardwarecutouts`, `knuckleblock`, `cyborgbeast07palm` |
| `parts/util/finger_base.scad` | `fingerbase`, `fingerhardwarecutouts`, `fingerbasesolid` |
| `parts/util/finger_mid.scad` | `fingermid` |
| `parts/util/finger_tip.scad` | `fingertip_curved_solid`, `fingertip_solid`, `fingertip_pad`, `fingertip` |
| `parts/thumb_tip.scad` | `thumbtip` |
| `parts/util/thermoform.scad` | `thermoform_mesh` |

`finger_tip_mold.scad` (the silicone casting mold) is not inlined — it is a separate print utility, not part of the hand assembly.

The top-level call is:

```openscad
mirror([mirrored ? 1 : 0, 0, 0])
    handlayout();
```

---

## 4. Conversion Patches

### 4.1 `fingerlayout` parameter-name bug

In the upstream `assembly.scad`, the assembly module passes a named argument `lengthMult` that does not match the module signature:

```openscad
// upstream — module signature and call site disagree
module fingerlayout(length=0) {
    fingertip_curved_solid(length = 17*lengthMult*fingerLength, ...);
    fingerbase(length = 20*lengthMult*fingerLength);
}

fingerlayout(lengthMult=indexProp*fingerLength);  // named arg ignored
```

In OpenSCAD, named arguments that do not match a parameter name are silently ignored. Inside the module body, `lengthMult` would resolve to an undefined variable (effectively `undef`), so the `length` expressions involving it would also be `undef`. The geometry still renders because OpenSCAD degrades gracefully on `undef` arithmetic, but all fingers are rendered at the same default size regardless of the `indexProp` / `ringProp` / `pinkyProp` values.

The fix renames the parameter to match what the body uses:

```openscad
// fixed
module fingerlayout(lengthMult = 1) {
    fingertip_curved_solid(length = 17*lengthMult, ...);
    fingerbase(length = 20*lengthMult);
}
```

Note that `fingerLength` is also removed from inside the expressions — it had been applied twice (once in the call site, once inside), which compounded the scaling. With the fix, the call site passes the already-multiplied value:

```openscad
fingerlayout(indexProp * fingerLength);
```

### 4.2 Deprecated `assign` construct

The upstream `fingertip_pad` module uses `assign($fn=16)` to temporarily override `$fn` for smoother cylinders:

```openscad
assign($fn=16) difference() { ... }   // assign removed in OpenSCAD 2019
```

Modern OpenSCAD (2019+) silently ignores unknown module calls, so `assign` is treated as a no-op. The `$fn` override is lost, but the geometry still renders. The conversion replaces `assign($fn=16) difference()` with a plain `difference()`. The affected cylinders are small silicone-pad attachment features where the resolution difference is not meaningful.

### 4.3 Stray `pad` named argument

Inside `fingertip_pad`, a call to `fingertip()` included `pad=false`:

```openscad
fingertip(length, pad=false, proximalHole=false, cutout=false);
```

The `fingertip` module does not declare a `pad` parameter, so the argument is silently ignored. The conversion removes it to eliminate the OpenSCAD customizer warning.

---

## 5. Anthropometric Parameter Mapping

### Scale factor derivation

The Flexy Beast inherits the Cyborg Beast sizing guide:

> Measure the knuckle width of the non-affected hand in mm. Add 5, then divide by 55.

In the upstream `config.scad`, the user sets `xScaleFactor`, `yScaleFactor`, and `zScaleFactor` manually to that computed value. In the platform integration, `palm_breadth_mm` is the input and the scale is derived automatically:

```openscad
xScaleFactor = (palm_breadth_mm + 5) / 55;
yScaleFactor = xScaleFactor;
zScaleFactor = xScaleFactor;
```

At the default `palm_breadth_mm = 83`, the scale is `(83 + 5) / 55 = 1.6`. The upstream defaults were 1.5 (x, y) and 1.6 (z); the platform uses a single isotropic scale because non-uniform scaling of the palm body distorts the cylindrical string-channel geometry.

The reference point for the formula is the **unscaled palm geometry**: the four finger positions in `hardwarecutouts` are at `i*7` for `i = [-3, -1, 1, 3]`, giving a knuckle span of 42 mm plus half a knuckle width on each side (`knuckleW/2 = 4.75` mm), for an unscaled total of ~51.5 mm. Multiplied by `xScaleFactor = 1.6`, this gives ~82.4 mm — approximately matching `palm_breadth_mm = 83`. The `+5` padding in the formula accounts for clearance so the user's hand fits inside the palm socket.

### Finger length derivation

The upstream model has a global `fingerLength` multiplier that scales all finger segments uniformly. At `fingerLength = 1` and `xScaleFactor = s`, each finger's total reach is:

```
fingerbase (length = 20) × yScaleFactor   +   fingertip_curved (length = 17) × yScaleFactor
= (20 + 17) × s
= 37s mm
```

This is an **internal design reference** — the reach of the printed part from the knuckle pin to the tip — not the anatomical MCP-to-tip length. At the default scale (`s = 1.6`), the internal reach is `37 × 1.6 = 59.2 mm`.

The anatomical middle finger is significantly longer than the printed part's reach because the proximal phalanx (MCP to PIP, roughly 35–40 mm) is represented by the palm-to-knuckle geometry, not the detachable finger part. The detachable finger covers only the distal two segments.

Rather than defining a separate REF constant, the mapping uses the derived scale directly:

```openscad
REF_FINGER_MM = 37;
fingerLength = middle_finger_length_mm / (REF_FINGER_MM * xScaleFactor);
```

At default values (`middle_finger_length_mm = 72`, `xScaleFactor = 1.6`): `fingerLength = 72 / 59.2 = 1.216`. This slightly extends the finger parts beyond the default Flexy Beast length, which is consistent with targeting a clinically measured anatomical length.

Clinicians should understand that `middle_finger_length_mm` drives the **distal two segments** of the finger part. The full MCP-to-tip anatomical length is still the correct input — the model uses it as a relative reference, not an absolute geometric target.

### Per-finger proportions

The upstream model has per-finger proportion variables (`indexProp`, `ringProp`, `pinkyProp`, `thumbProp`) relative to the middle finger (`middleProp = 1`). In the platform integration these are derived from the canonical per-finger length inputs:

```openscad
indexProp  = index_finger_length_mm  / middle_finger_length_mm;
ringProp   = ring_finger_length_mm   / middle_finger_length_mm;
pinkyProp  = pinky_finger_length_mm  / middle_finger_length_mm;
thumbProp  = thumb_length_mm         / middle_finger_length_mm;
```

This means all four lengths are expressed relative to the middle finger, which is anatomically correct: the middle finger is the longest and the natural reference for inter-finger scaling.

### Parameter table

| Platform parameter | Config variable | Derivation | Active / stored |
|---|---|---|---|
| `palm_breadth_mm` | `xScaleFactor` | `(palm_breadth_mm + 5) / 55` | Active — drives all dimensions uniformly |
| `middle_finger_length_mm` | `fingerLength` | `middle_finger_length_mm / (37 × xScaleFactor)` | Active — drives finger reach for all fingers |
| `index_finger_length_mm` | `indexProp` | `index / middle` | Active — scales index relative to middle |
| `ring_finger_length_mm` | `ringProp` | `ring / middle` | Active — scales ring relative to middle |
| `pinky_finger_length_mm` | `pinkyProp` | `pinky / middle` | Active — scales pinky relative to middle |
| `thumb_length_mm` | `thumbProp` | `thumb / middle` | Active — scales thumb relative to middle |
| `palm_length_mm` | — | Not used | Not mapped — palm must scale isotropically |
| `palm_thickness_mm` | — | Not used | Not mapped — palm must scale isotropically |

`palm_length_mm` and `palm_thickness_mm` are not represented as parameters because the Flexy Beast palm geometry is not designed for independent X/Y/Z scaling: the string channels, joint slots, and knuckle cutouts are routed at angles that assume isotropic scale. Separate length or thickness inputs would distort these features.

### Validation

An end-to-end simulation (real `/edit` flow: AI sizing → STL export, then `trimesh`
measurement of every exported part) confirms the mapping above holds in the produced
geometry. Across child/woman/man/default configs the palm length scales **linearly**
with `palm_breadth_mm` (length / breadth ≈ **1.49–1.52**, constant), and each finger
part scales with its `*_finger_length_mm` input. Sized to the same hand, the part
envelopes also match the daprice 160 % demo STLs to within ~1 % on the palm. Full
prompts, AI-applied parameters and per-part dimensions:
[`docs/flexy-beast-ai-sim/`](flexy-beast-ai-sim/flexy-beast_ai-sizing-dimensional-report_2026-06-28.md).

The same run surfaced (and the platform then fixed, v14.16.0) a grounding-matcher bug
that had been anchoring every patient on a male population profile regardless of the
described sex/age — see `docs/ai_anthropometric_validation.md` §2.4. Flexy Beast is a
consumer of that grounding path, so the fix improves its sizing for women and children.

---

## 6. Hardware Parameters

Two hardware parameters are exposed that have no analogue in the other platform models:

**`joint_dia`** (default 7 mm) — diameter of the cylindrical hole cut into each knuckle block and thumb joint to accept the flexy joint insert. The upstream documentation recommends reducing this to 5 mm for smaller children's hands to prevent the joint from tearing through the printed plastic.

**`joint_thick`** (default 4 mm) — thickness of the slot cut through the top of each knuckle block. This must match the thickness of the flexy joint material being used (Filaflex rod or cast silicone). Reducing to 2 mm is recommended alongside reducing `joint_dia` for small hands.

---

## 7. Finger Pad Hollows

The `finger_pads` parameter (default `true`) controls whether the fingertip modules hollow the dorsal face of each fingertip to accept a cast or printed flexible pad. When `true`, `fingertip_curved_solid` and `thumbtip` call `fingertip_pad()` internally to subtract the hollow shape.

The pad cavity includes two small cylindrical retention pegs and a groove around the perimeter that grip a flexible silicone pad by compression. Pads can be:
- Cast in silicone using `finger_tip_mold.scad` from the upstream source (not included in the platform model — render separately from the upstream files).
- Printed directly in flexible filament using the same mold with `padPositive = true`.

Setting `finger_pads = false` produces solid fingertips suitable for dry-finger use or when pads are not needed.

---

## 8. Thermoform Mesh

The `show_thermoform` parameter (default `true`) renders a perforated mesh inside the palm socket. The mesh is intended to be printed in PLA and then heat-formed directly to the patient's residual limb for a custom fit.

The mesh is generated by `thermoform_mesh()` clipped to the palm interior void (`cyborgbeast07palminsidespace()`). The hole pattern uses 1.75 × 5.5 mm oval cutouts on a staggered grid, leaving enough material for structural integrity while allowing air circulation.

For patients with sensitive skin or where a thermoformed fit is not needed, disabling `show_thermoform` renders a solid palm socket interior.

---

## 9. Flexy Joints (Finger Hinges)

The Flexy Beast's defining feature is that flexible connector pieces — the **flexy
joints** — replace the Cyborg Beast's Chicago screws and elastics. The upstream BOM
lists **10× Flexy Joint** (two per finger and two for the thumb: one at each MCP
knuckle and one at each base↔tip joint). A separate reconstruction,
`Finger_Hinge_Plate.scad`, held those connectors as a fixed print plate whose
dogbone/eyelet outlines were traced from an STL — geometry that could not follow the
hand's parameters.

That plate is now **generated parametrically inside `flexy_beast.scad`** instead of
imported. A single `flexy_joint()` module builds the dogbone-form living hinge — two
lobes (each with a pin bore) joined by a thin flexing web — with every dimension
derived from the joint hardware and hand scale:

```openscad
h_wall   = 1.2;                      // material around each pin bore
h_lobe_r = jointDia/2 + h_wall;      // lobe radius (wraps the pin)
h_web_t  = jointThick;               // flexing web thickness = slot thickness
h_len    = knuckleW * xScaleFactor;  // length along the pin (fills the slot width)
h_span   = 8 * xScaleFactor;         // lobe centre-to-centre (knuckle-gap bridge)
h_bore   = jointDia;                 // pin clearance bore through each lobe
```

These map onto the original measured dogbone (extrude height 12 mm ≈ `knuckleW × 1.26`,
lobe span 10 mm ≈ `8 × 1.26`), so the recognisable connector form is preserved while
it now tracks `joint_dia`, `joint_thick` and the hand scale.

**Placement.** The connectors are positioned at the exact pin bores drilled by
`fingerhardwarecutouts`, in the finger's own frame:

- Each finger emits its two joints from inside `fingerlayout(hinge=true)`, so they
  inherit the finger's assembled pose and length scaling (the PIP joint slides along
  the finger as `*_finger_length_mm` changes).
- The thumb emits its two from `thumb_hinges()` inside the thumb group frame.
- Each connector is oriented (`rotate([90,90,0])`) so its **pin bore runs across the
  finger width** — coaxial with the pin the palm/finger knuckles are drilled for —
  its span runs along the finger length and its thin flexing web faces dorsally. One
  lobe is seated on the segment's own pin bore and the other reaches into the
  neighbouring segment (MCP → toward the palm knuckle, PIP → toward the fingertip),
  so the dogbone bridges the joint gap the way the printed flexible part does.
- In `print_layout`, `hinge_plate()` lays all ten connectors flat in a grid — a
  single printable unit for flexible filament (Filaflex/TPU).

**Controls.** `show_hinges` (default on) toggles the connectors; `color_hinge` sets
their preview/3MF colour. A dedicated **Flexy joints (plate)** part (`show_hinges`
toggle) exports the whole plate on its own; because it is one printable unit it emits
all ten connectors regardless of which finger toggles are set.

## 10. Attribution

Original design: **Flexy Beast** by daprice, https://github.com/daprice/Flexy-Beast, licensed CC BY-SA 4.0.

Based on:
- Parametric Cyborg Beast by MakerBlock, https://www.thingiverse.com/thing:320173
- Flexy Hand by Steve Wood / Gyrobot, https://www.thingiverse.com/thing:380665

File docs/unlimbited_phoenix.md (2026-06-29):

# UnLimbited Phoenix Hand — Integration Notes

This document explains how the Team UnLimbited Phoenix Hand was integrated into the
AI Parametric Prosthetic Hand Generator platform: the source design, the model
structure, the (single) anthropometric mapping, and the scale-floor behaviour.

## 1. Source Design

**Team UnLimbited Phoenix Hand V1.0**, by Stephen Robert Davies & Drew Murray / Team
UnLimbited (original Phoenix Hand by Jason Bryant), licensed **CC BY-NC-SA 4.0**
(teamunlimbited.org). Upstream is a Thingiverse Customizer thing
([thing:1674320](https://www.thingiverse.com/thing:1674320)): the user picks left/right
and a scale, and a `.zip` of all parts is generated at that scale.

The geometry is **not** procedural — the palm, fingers, phalanx, pins, tension box and
gauntlet are fixed meshes captured as OpenSCAD `polyhedron()` point/face arrays. The
palm used here is the **Thermo-palm Phoenix Palm** (`Phoenix_Thermo_Palm_2`), whose
unscaled (100%) bounding box is **82.17 × 91.96 × 30.55 mm**.

### Source files

| Repo path | Purpose |
|---|---|
| `models/active/unlimbed_phoenix_hand/UnLimbitedPhoenix.scad` | the integrated, self-contained model |
| `tests/UnLimbited_Arm_V2.2.scad` | upstream Team UnLimbited source (arm + hand), used as the dimensional **reference** (its `part = 5` palm embeds the same `Phoenix_Thermo_Palm_2` mesh) |

## 2. Approach: Self-Contained Single File

As with the other models, the upstream multi-file Customizer was consolidated into one
self-contained `.scad` with the meshes embedded inline (no `use<>`, `include<>`, or
`import()` — so it runs in OpenSCAD-WASM with no dependency files). The configurator
declares **no `parts`** in `models-config.json`, so "Export STL" produces a **single
file** — whichever part `part` selects (default `Palm`).

## 3. What Was Built

A `print_part()` dispatcher renders one part at a time, scaled by `HandPerc/100` and
mirrored for the right hand:

| `part` value | Module | Notes |
|---|---|---|
| `Palm` *(default)* | `Phoenix_Thermo_Palm_2()` | the exported part by default |
| `Box` | `3Pin_Tensioner_Box()` | wrist tension box |
| `TPins` | `3Tensionpins()` | tension pins |
| `Fingers` | `Phoenix_Fingers_Left()` | finger tips |
| `Phalanx` | `Phoenix_Phalanx_Left()` | proximal phalanxes |
| `Pins` | `Phoenix_Pins()` | hinge pins |
| `Gauntlet` | `Gauntlet_V4()` | Reverse-Dovetail thermo gauntlet |
| `Jig` | — | assembly jig |

`LeftRight` (`Left`/`Right`) mirrors the geometry along X.

## 4. Anthropometric Parameter Mapping

Unlike the Flexy Beast and Paraglider, the Phoenix mesh is a **single fixed shape that
can only be scaled uniformly** — there is one anthropometric input:

| Platform parameter | Derivation | Active / stored |
|---|---|---|
| `palm_breadth_mm` (range **82–131**) | `HandPerc = palm_breadth_mm / 82 × 100`, clamped **100–160%** | Active — drives the uniform print scale |
| `HandPerc_override` (range 0–160) | `0` = auto (use the line above); `100–160` = set the scale directly | Active — manual escape hatch |

```openscad
REF_PALM_BREADTH = 82;   // breadth of the unscaled (100%) Phoenix mesh
HandPerc = HandPerc_override > 0
    ? max(100, min(160, HandPerc_override))
    : max(100, min(160, palm_breadth_mm / REF_PALM_BREADTH * 100));
```

### The 100% floor (and why)

The Phoenix mesh **cannot be printed below its native 100% size** (≈82 mm palm breadth);
shrinking it further produces walls and channels too thin to print and assemble. The
model therefore **clamps the scale to 100–160%** and the `palm_breadth_mm` slider starts
at 82. For hands narrower than ~82 mm, use a model that scales down further — the
**Flexy Beast** (the model help says so explicitly).

> **Both scale paths are floored (fix v14.18.0).** `HandPerc_override`'s declared range
> is `[0:160]`, but only `0` (auto) and `100–160` (direct) are meaningful — the `1–99`
> band is a dead zone. It previously had **no floor**, so a value like `76` scaled the
> palm to 76% (62 mm), bypassing the 100% minimum that `palm_breadth_mm` enforces. The
> AI-sizing simulation hit exactly this (a child profile produced `HandPerc_override = 76`).
> The override branch now applies the same `max(100, min(160, …))` clamp, so **neither**
> path can drop below 100%. See `docs/phoenix-ai-sim/` §5.

## 5. Validation

An end-to-end simulation (real `/edit` flow: AI sizing → STL export → `trimesh`
measurement) confirms the integration reproduces the upstream Phoenix palm **exactly**:
the exported palm equals the `tests/UnLimbited_Arm_V2.2.scad` reference mesh × `HandPerc/100`
to within ≤0.06 mm, and the 100% exports are byte-identical to the 82.17 mm reference. It
also surfaced (and the platform fixed) the override floor gap above, and confirmed the
size floor for the small profiles. Full prompts, AI-applied parameters and dimensions:
[`docs/phoenix-ai-sim/`](phoenix-ai-sim/unlimbited-phoenix-hand_ai-sizing-dimensional-report_2026-06-28.md).

Grounding for this model anchors only `palm_breadth_mm` (its single anatomical input);
see the matcher notes in `ai_anthropometric_validation.md` §2.4.

## 6. Attribution

Team UnLimbited Phoenix Hand V1.0 — Stephen Robert Davies & Drew Murray / Team UnLimbited;
original Phoenix Hand by Jason Bryant. Licensed **CC BY-NC-SA 4.0**
([teamunlimbited.org](https://www.teamunlimbited.org)). Integrated here with the geometry
unchanged; only the sizing front-end (anthropometric `palm_breadth_mm` → uniform print
scale) was added.

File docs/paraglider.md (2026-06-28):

# Paraglider Hand — Integration Notes

This document explains how the Paraglider / Flexible Flyer prosthetic hand design was integrated into the AI Parametric Prosthetic Hand Generator platform. It covers the source design, what was built, how the anthropometric parameter alignment was achieved, and the trade-offs involved.

---

## 1. Source Design

The **Paraglider Hand** (also called the Flexible Flyer) is an open-source body-powered prosthetic wrist hand designed by Marcus Mendenhall in 2020, released under CC BY-SA 4.0. It is a remix of three established e-NABLE designs: the Phoenix v2, the Unlimbited Phoenix v3, and the Phoenix Reborn.

The design's primary contribution over its predecessors is the use of **commercial metal hardware** — 1/16-inch steel dowel pins, 3 mm screws, or 13-gauge finishing nails — as finger pivot pins, with optional self-lubricating plastic tubing (Delrin or PTFE) inserted as a bearing. Compared to 3D-printed plastic pins, this makes joints significantly smoother and stronger. Hole diameters in both the palm and the finger phalanges are computed parametrically in OpenSCAD to match the selected hardware style, with a configurable clearance to account for individual printer tolerances.

### Source files

| File | Role |
|---|---|
| `fingerator.scad` | Generates all finger parts: long fingertip, short fingertip, finger phalanx, thumb tip, thumb phalanx |
| `paraglider_palm_left.scad` | Generates the palm body by applying CSG operations to an imported Phoenix v2 STL |
| `pipe.scad` | Helper library for routing curved string/elastic channels through the palm |
| `palm_left_v2_nobox.stl` | Repaired Phoenix v2 palm mesh (support box removed in MeshMixer, holes patched) |

`fingerator.scad` is entirely self-contained native OpenSCAD geometry — no imports. `paraglider_palm_left.scad` imports `pipe.scad` and `palm_left_v2_nobox.stl`.

---

## 2. Source File Patches

> **Update (2026-06-15):** the vendored OpenSCAD WASM build has since been upgraded to **2025.03.25**, which fully supports the `each` keyword (added upstream in 2019.05). The `each`→`concat()` rewrites described in §2.1 are therefore **no longer required** — they are retained in the unified `paraglider_hand` copy because they are harmless and already tested, but the variant palms and accessories added later (§12) ship with the **raw upstream `each` usage** and parse correctly. The double-comma fix in §2.2 *is* still required (it is a genuine syntax error rejected by current OpenSCAD).

### 2.1 The `each` keyword in list constructors (historical)

When this model was first integrated, the WASM build of OpenSCAD predated reliable `each` support. OpenSCAD 2019.05 introduced the `each` keyword for splatting a list into a parent list comprehension:

```openscad
// upstream
shape = [[-1.5,-1],[1.5,-1], each 1.5*[for(th=[0:30:179]) [cos(th), sin(th)]]]*shapescale;
```

On that older build the file failed to load — no modules were defined, and `scaled_palm()` became undefined. The original fix replaced `each` with `concat()` (kept in the unified copy):

```openscad
// patched
shape = concat(
    [[-1.5,-1],[1.5,-1]],
    [for(th=[0:30:179]) 1.5*[cos(th), sin(th)]]
)*shapescale;
```

A second instance in the same file used `each` inside a `translate()` call:

```openscad
// upstream
for(xy=holes) translate([each xy, 0.001]) cylinder(...);

// patched
for(xy=holes) translate([xy[0], xy[1], 0.001]) cylinder(...);
```

### 2.2 Double comma in array literal

Line 85 of the upstream file contained a double comma producing an `undef` element:

```openscad
// upstream
[[20.68,-38,8],,[0,90,0]]

// patched
[[20.68,-38,8],[0,90,0]]
```

### 2.3 Patched file location

Rather than modifying the upstream files in `flexible_flyer-master/files/`, patched copies are maintained at:

```
models/active/paraglider_hand/paraglider_palm_left.scad
models/active/paraglider_hand/fingerator.scad
models/active/paraglider_hand/pipe.scad
```

`pipe.scad` uses `each` inside its channel-routing modules; on the current 2025.03.25 WASM build this parses fine, and in any case those modules are bypassed by the `do_channels()` override by default. `fingerator.scad` requires no patches.

The palm base mesh now lives as a **real file** at `models/active/paraglider_hand/palm_left_v2_nobox.stl` (a copy of the repaired Phoenix v2 mesh). The earlier integration used a symlink into a `flexible_flyer-master/` working copy; when that directory was removed the symlink dangled and the `import()` silently produced empty geometry. The model file set is now self-contained.

---

## 3. What Was Built

A master assembly SCAD file was created at:

```
models/active/paraglider_hand/paraglider_hand.scad
```

This file is a **thin parametric wrapper** — it does not reproduce or copy the geometry of the source files. Instead it:

1. Declares the canonical anthropometric parameters and derives scale factors from them.
2. Re-declares every variable that the source file modules reference internally, so that OpenSCAD's dynamic scoping mechanism routes the correct values into those modules at render time.
3. Calls `scaled_palm()` from `paraglider_palm_left.scad` for the palm section.
4. Defines shared finger modules (`_long_finger`, `_short_finger`, `_finger_phalanx`, etc.) that wrap fingerator calls with per-finger scale factors.
5. Renders either an **assembled view** (default) — finger parts positioned at the palm's knuckle pin coordinates — or a **flat print layout** — all parts laid side by side for slicing.

### Module overrides

Two modules from `paraglider_palm_left.scad` are overridden in the wrapper:

**`do_labels()`** — The WASM build has no fontconfig, so `text()` calls produce "Can't get font" warnings and empty geometry. The override passes children through without calling `text()`:

```openscad
module do_labels() { children(); }
```

**`do_channels()`** — The channel CSG (`plug_old_channels`, `reborn_channels` from `pipe.scad`) involves complex swept-tube boolean operations that stress the Manifold backend significantly. The override skips channel routing by default and only applies the structural end-shave cut, dramatically reducing render time. Set `show_channels = true` to enable full channel routing for a print-ready export.

---

## 4. Variable Scoping: `use<>` is Lexical, Not Dynamic

> ⚠️ **Correction (v14.17.0).** Earlier revisions of this section claimed that
> `use<>` resolves a module's variables by *dynamic* scoping (from the caller). That
> is **wrong**, and the mistaken assumption caused a real sizing bug — the Reborn
> palm silently ignored `palm_breadth_mm`. The accurate rule and the fix are below.

OpenSCAD's `use <file.scad>` imports the **modules and functions** defined in a file
but does **not** import its top-level variable bindings and does **not** run its
top-level geometry. For ordinary (non-`$`) variables, references inside an imported
module are resolved **lexically** — against the top-level globals of the file that
*defines* the module, **not** the file that calls it. Only `$`-prefixed **special
variables** are dynamically scoped from the call site.

Consequence: `paraglider_palm_left.scad` defines `overall_scale = 1.25` at its top
level, and `scaled_palm()` reads *that* value. When `paraglider_hand.scad` computes
`overall_scale = palm_breadth_mm / 66.4` and then calls `scaled_palm()` via
`use <paraglider_palm_left.scad>`, the module still uses **1.25** — the wrapper's
value is invisible to it. So the **Reborn palm did not resize to `palm_breadth_mm`**:
every patient got the 83 mm "medium" palm, while the fingers (which receive their
scale as an explicit module argument) scaled correctly.

**Fix (v14.17.0).** `scaled_palm()` already bakes scale 1.25, so the missing
anthropometric scale is re-applied at the Reborn call site:

```openscad
if (palm_style == "UnlimbitedV3") V3_scaled_palm();
else scale(overall_scale / 1.25) scaled_palm();  // 1.25 × overall_scale/1.25 = palm_breadth_mm/66.4
```

Verified end-to-end in [`docs/paraglider-ai-sim/`](paraglider-ai-sim/paraglider-hand_ai-sizing-dimensional-report_2026-06-28.md)
(palm now scales: breadth 62→84.9 mm, 83→113.7 mm unchanged, 96→131.5 mm). The
`UnlimbitedV3` palm was never affected: `pg_v3palm.scad` is brought in with
**`include`** (see the Namespacing section below), which *does* share top-level scope,
so its `V3_overall_scale` resolves to the value set in the dispatcher. The same
lexical rule is exactly why the variant bundles cannot simply be `use`d — they are
namespaced and `include`d instead.

The variables below are the palm file's own top-level globals that `scaled_palm()`
depends on (for reference; in the unified copy they live in the wrapper alongside the
`use`):

```openscad
slot_dx = [[[10,0,0],0],[[-4,0,0],0],[[-18,-4,0],0],[[-32,-10,0],0]];
pin_coordinates = [
    [[-35.4,-38,8],[0,90,0]],    // left wrist
    [[20.68,-38,8],[0,90,0]],    // right wrist
    [[6.6,39.5,6.0],[0,90,0]],   // index + middle knuckle
    [[-16,35.5,6.0],[0,90,0]],   // ring knuckle
    [[-29.5,29.5,6.0],[0,90,0]], // pinky knuckle
    [[31,0,6.0],[0,90,50]]       // thumb MCP
];

initial_rotation   = 33.5;
nominal_slotwidth  = 6;
adjusted_tabwidth  = nominal_slotwidth - nominal_clearance / global_scale;
nut_size           = 5.5;
bolt_head_dia      = 5.5 + 0.3;
```

---
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

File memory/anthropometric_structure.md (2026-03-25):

---
name: Anthropometric data model and derivation pipeline
description: Primary input fields, derived geometry parameters, and the 4-layer hierarchy in the anthropometric importer
type: project
---

The anthropometric pipeline follows a strict 4-layer hierarchy:

1. **Primary inputs** — directly measured by clinician or from dataset
2. **Derived geometry** — computed from primaries (phalanx segments, socket geometry)
3. **Functional** — per-digit total lengths, joint positions
4. **Manufacturing/constraint** — clearance, hardware standard, reinforcement zones
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

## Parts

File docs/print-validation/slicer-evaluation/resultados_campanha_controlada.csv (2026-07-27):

modelo | perfil | condicao | estado | n_pecas_entrada | n_placas_A1 | tempo_estimado_total | tempo_s_total | comprimento_filamento_mm | massa_g | volume_cm3 | custo_eur_a_36.29_por_kg | n_camadas_max | altura_max_mm | footprint_placa1_x_mm | footprint_placa1_y_mm | footprints_todas_placas | avisos
Flexy Beast | child_8 | A1 / bico 0,4 / PLA Basic / 0,20 mm / 2 paredes / 15% grelha / SEM suportes / brim auto | SLICED | 12 | 1 | 6h39m34s | 23974.9 | 27387.6 | 83.0 | 65.87 | 3.01 | 186 | 37.1 | 161.7 | 143.2 | 161.7x143.2 | It seems object OpenSCAD Model has floating cantilever. Please re-orient the object or enable support generation.
Flexy Beast | teen_15 | A1 / bico 0,4 / PLA Basic / 0,20 mm / 2 paredes / 15% grelha / SEM suportes / brim auto | SLICED | 12 | 1 | 9h51m52s | 35512.6 | 43180.9 | 130.87 | 103.86 | 4.75 | 225 | 45.0 | 194.1 | 190.5 | 194.1x190.5 | It seems object OpenSCAD Model has floating cantilever. Please re-orient the object or enable support generation.
Flexy Beast | adult_28 | A1 / bico 0,4 / PLA Basic / 0,20 mm / 2 paredes / 15% grelha / SEM suportes / brim auto | SLICED | 12 | 2 | 12h34m14s | 45254.4 | 55811.9 | 169.15 | 134.24 | 6.14 | 256 | 51.1 | 134.1 | 177.2 | 134.1x177.2 | 174.6x124.0 | It seems object OpenSCAD Model has floating cantilever. Please re-orient the object or enable support generation. ; It seems object OpenSCAD Model has floating regions. Please re-orient the object or enable support generation.
Flexy Beast | elderly_70 | A1 / bico 0,4 / PLA Basic / 0,20 mm / 2 paredes / 15% grelha / SEM suportes / brim auto | SLICED | 12 | 2 | 10h52m57s | 39177.7 | 47602.0 | 144.27 | 114.5 | 5.24 | 245 | 49.0 | 195.4 | 188.9 | 195.4x188.9 | 40.2x36.6 | It seems object OpenSCAD Model has floating regions. Please re-orient the object or enable support generation.
Paraglider Hand | child_8 | A1 / bico 0,4 / PLA Basic / 0,20 mm / 2 paredes / 15% grelha / SEM suportes / brim auto | SLICED | 7 | 1 | 4h22m47s | 15767.4 | 16522.2 | 50.07 | 39.74 | 1.82 | 145 | 29.0 | 125.9 | 166.0 | 125.9x166.0 | (nenhum)
Paraglider Hand | teen_15 | A1 / bico 0,4 / PLA Basic / 0,20 mm / 2 paredes / 15% grelha / SEM suportes / brim auto | SLICED | 7 | 1 | 6h45m18s | 24318.2 | 27695.5 | 83.94 | 66.62 | 3.05 | 179 | 35.9 | 140.6 | 178.9 | 140.6x178.9 | (nenhum)
Paraglider Hand | adult_28 | A1 / bico 0,4 / PLA Basic / 0,20 mm / 2 paredes / 15% grelha / SEM suportes / brim auto | SLICED | 7 | 1 | 8h55m41s | 32141.4 | 38449.4 | 116.53 | 92.48 | 4.23 | 207 | 41.4 | 195.5 | 194.5 | 195.5x194.5 | (nenhum)
Paraglider Hand | elderly_70 | A1 / bico 0,4 / PLA Basic / 0,20 mm / 2 paredes / 15% grelha / SEM suportes / brim auto | SLICED | 7 | 1 | 7h09m05s | 25746.0 | 29627.5 | 89.79 | 71.26 | 3.26 | 193 | 38.7 | 180.2 | 176.5 | 180.2x176.5 | It seems object OpenSCAD Model has floating regions. Please re-orient the object or enable support generation.
UnLimbited Phoenix | child_8 | A1 / bico 0,4 / PLA Basic / 0,20 mm / 2 paredes / 15% grelha / SEM suportes / brim auto | SLICED | 8 | 2 | 7h29m44s | 26984.7 | 30673.7 | 92.96 | 73.78 | 3.37 | 189 | 37.8 | 181.0 | 178.4 | 181.0x178.4 | 64.7x66.0 | (nenhum)
UnLimbited Phoenix | teen_15 | A1 / bico 0,4 / PLA Basic / 0,20 mm / 2 paredes / 15% grelha / SEM suportes / brim auto | SLICED | 8 | 2 | 8h30m45s | 30645.2 | 36335.2 | 110.12 | 87.4 | 4.0 | 202 | 40.5 | 192.9 | 193.8 | 192.9x193.8 | 69.2x70.8 | (nenhum)
UnLimbited Phoenix | adult_28 | A1 / bico 0,4 / PLA Basic / 0,20 mm / 2 paredes / 15% grelha / SEM suportes / brim auto | SLICED | 8 | 2 | 8h56m20s | 32180.3 | 38179.8 | 115.71 | 91.83 | 4.2 | 207 | 41.4 | 154.1 | 154.5 | 154.1x154.5 | 148.7x167.4 | (nenhum)
UnLimbited Phoenix | elderly_70 | A1 / bico 0,4 / PLA Basic / 0,20 mm / 2 paredes / 15% grelha / SEM suportes / brim auto | SLICED | 8 | 2 | 7h49m09s | 28149.6 | 32412.0 | 98.23 | 77.96 | 3.56 | 193 | 38.7 | 185.3 | 182.7 | 185.3x182.7 | 66.2x67.6 | (nenhum)

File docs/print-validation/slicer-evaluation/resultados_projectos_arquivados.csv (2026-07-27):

projecto | ficheiro | programa | versao | impressora | bico_mm | material | perfil_processo | altura_camada_mm | camada_inicial_mm | paredes | top_layers | bottom_layers | enchimento | suportes | aba | orientacao_mantida | tempo_estimado | comprimento_filamento_mm | massa_g | volume_cm3_por_massa_densidade | custo_eur_a_36.29_por_kg | n_objetos | footprint_x_mm | footprint_y_mm | altura_max_mm | n_camadas | fatiamento | avisos
Flexy Beast (15 anos, PLA) | flexy_beast_teen_15_print.3mf | Bambu Studio | 01.10.02.76 | Bambu Lab A1 | 0.4 | PLA (Bambu PLA Basic @BBL A1) | 0.20mm Standard @BBL A1 | 0.24 | 0.2 | 2 | 4 | 3 | 15% grelha | Sim - árvore orgânica (só na base, regiões críticas, limiar 35 graus) | auto_brim 5 mm | Sim (projecto fatiado como preparado) | 2h 21m 50s | 18645.87 | 56.51 | 44.85 | 2.05 | 10 | 158.2 | 121.5 | 63.7 | 266 | Sucesso | (nenhum)
UnLimbited Phoenix (15 anos, PLA) | unlimbed_phoenix_hand_teen_15_print_project.3mf | Bambu Studio | 01.10.02.76 | Bambu Lab A1 | 0.4 | PLA (Bambu PLA Basic @BBL A1) | 0.20mm Standard @BBL A1 | 0.24 | 0.2 | 2 | 4 | 3 | 15% grelha | Sim - árvore orgânica (só na base, regiões críticas, limiar 35 graus) | auto_brim 5 mm | Sim (projecto fatiado como preparado) | 5h 12m 44s | 40756.68 | 123.52 | 98.03 | 4.48 | 8 | 222.6 | 214.7 | 40.5 | 169 | Sucesso | (nenhum)
UnLimbited Phoenix (15 anos, PETG) | unlimbed_phoenix_hand_teen_15_print_project_PETG.3mf | Bambu Studio | 01.10.02.76 | Bambu Lab A1 | 0.4 | PETG (Bambu PETG Basic @BBL A1) | 0.20mm Standard @BBL A1 | 0.24 | 0.2 | 2 | 4 | 3 | 15% grelha | Sim - árvore orgânica (só na base, regiões críticas, limiar 35 graus) | auto_brim 5 mm | Sim (projecto fatiado como preparado) | 5h 51m 52s | 39094.09 | 117.54 | 94.03 | 4.27 | 8 | 222.2 | 211.5 | 40.5 | 169 | Sucesso | (nenhum)
Paraglider Hand (15 anos, PLA) | paraglider_15_teen_prusa_print_profile.3mf | PrusaSlicer | 2.8.1+linux-x64-GTK3-202409181416 | Prusa MINI (perfil MINIIS) | 0.4 | PLA (Prusament PLA @MINIIS) | 0.20mm SPEED @MINIIS 0.4 | 0.2 | 0.2 | 2 | 5 | 4 | 15% grelha | Nao (support_material=0) | Nao (outer_only, largura 0) | Sim (projecto fatiado como preparado) | 2h 32m 11s | 12727.61 | 37.96 | 30.61 | 1.38 | 5 | 98.2 | 96.9 | 21.4 | nao reportado (PrusaSlicer) | Sucesso | Low bed adhesion (thumb,pinky,ring,middle,index); consider supports+brim

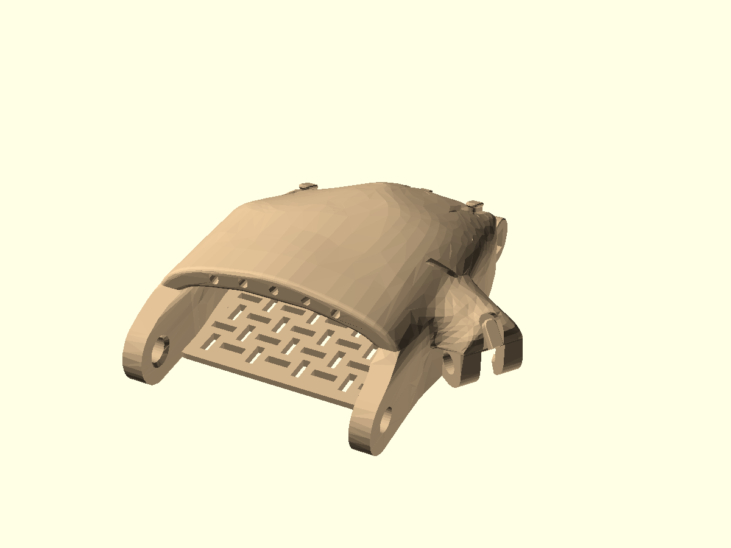
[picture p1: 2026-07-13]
docs/print-validation/growth-series/unlimbed_phoenix_hand/age_15/parts/palm.png

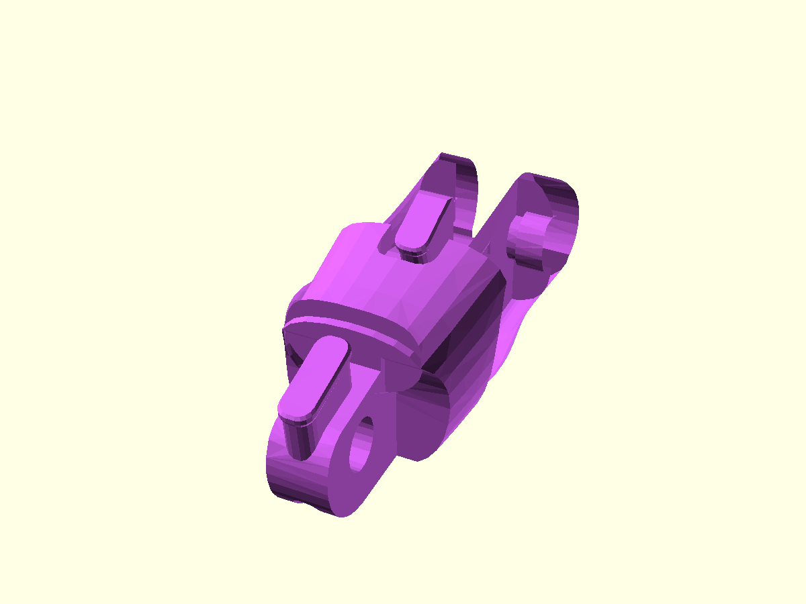
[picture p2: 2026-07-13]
docs/print-validation/growth-series/unlimbed_phoenix_hand/age_12/parts/thumb.png

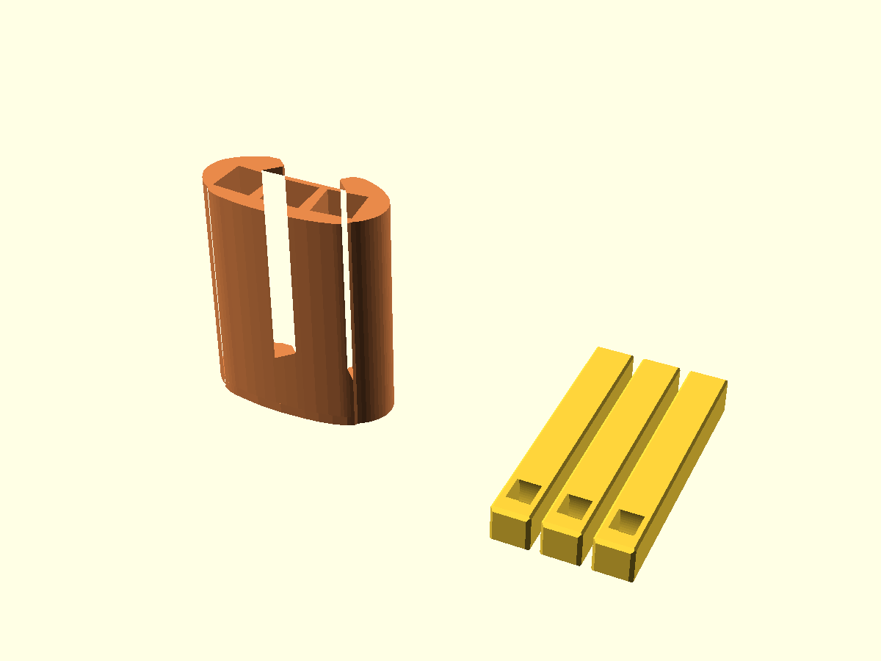
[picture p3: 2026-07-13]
docs/print-validation/growth-series/unlimbed_phoenix_hand/age_15/parts/tensioner.png

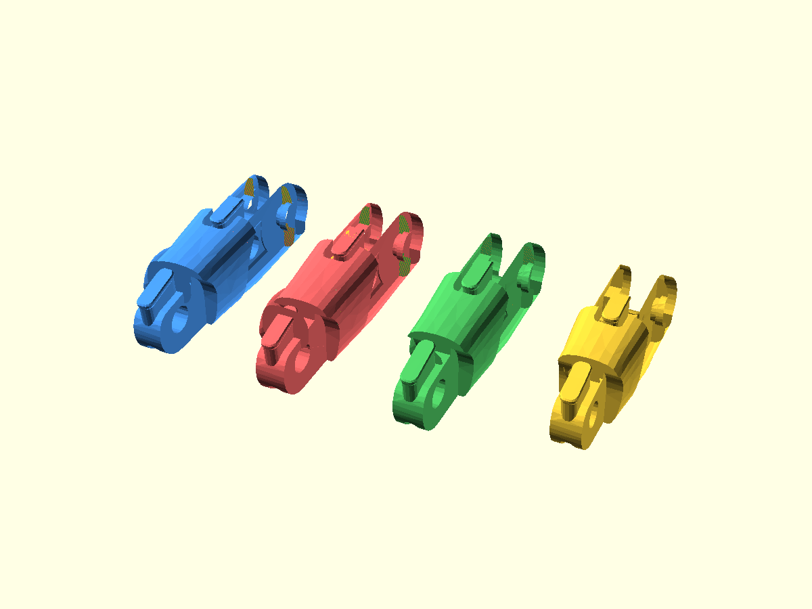
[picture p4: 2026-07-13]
docs/print-validation/growth-series/unlimbed_phoenix_hand/age_15/parts/fingers.png

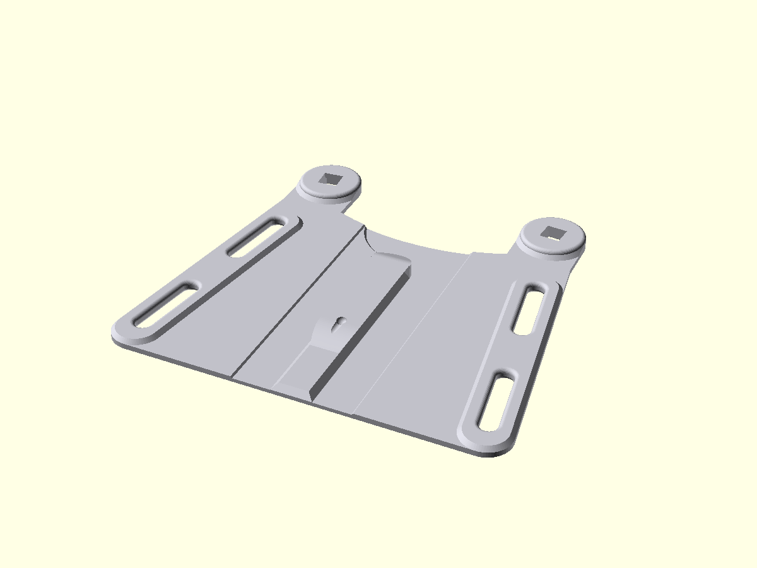
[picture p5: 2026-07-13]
docs/print-validation/growth-series/unlimbed_phoenix_hand/age_15/parts/gauntlet.png

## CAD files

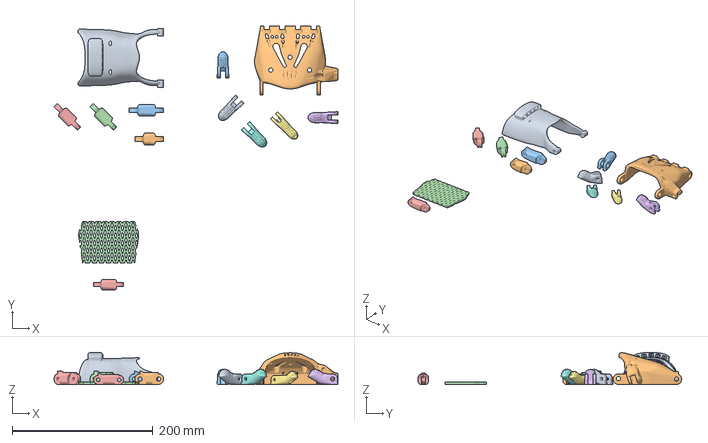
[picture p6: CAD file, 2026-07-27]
docs/print-validation/cyborg_beast_teen_15_print_project.3mf
403.6 x 374.5 x 45.5 mm

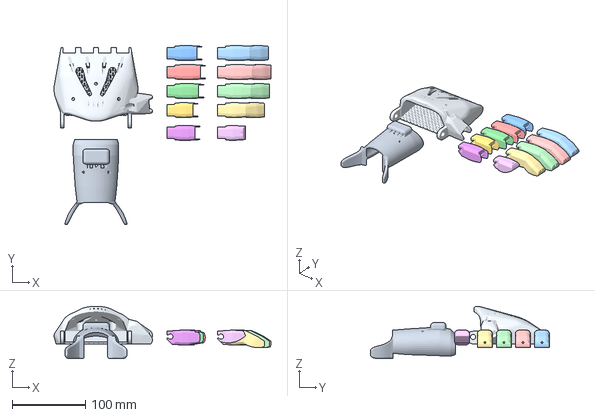
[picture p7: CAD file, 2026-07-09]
docs/print-validation/flexy_beast/adult_28/flexy_beast_adult_28.3mf
295.7 x 243.8 x 71.2 mm

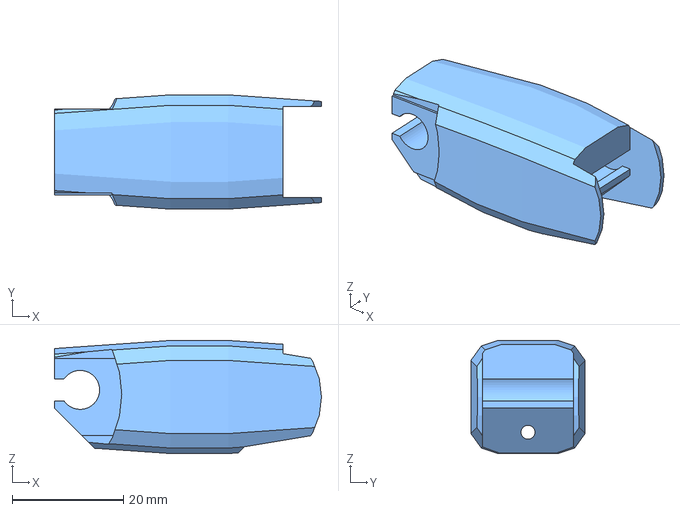
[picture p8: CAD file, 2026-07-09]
docs/print-validation/flexy_beast/adult_28/parts/index_base.3mf
48.0 x 20.5 x 20.3 mm

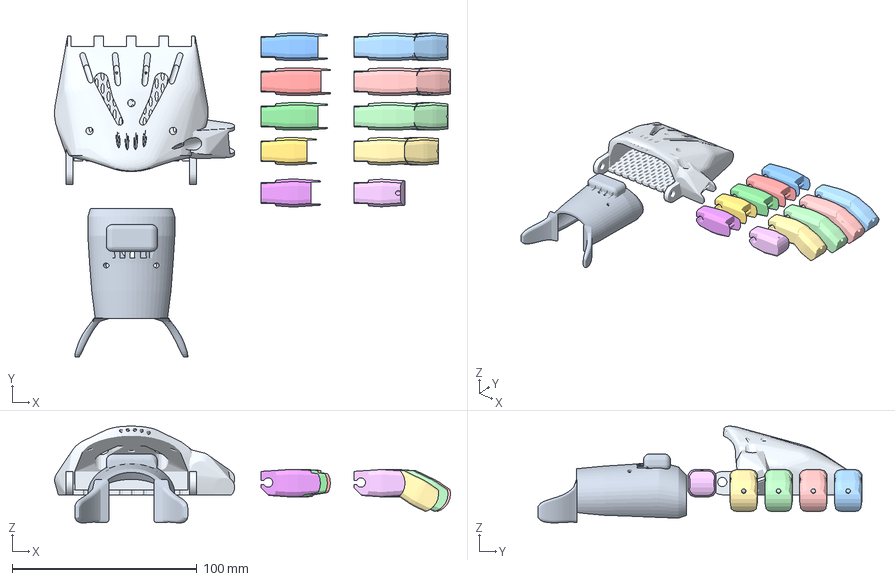
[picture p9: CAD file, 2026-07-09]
docs/print-validation/flexy_beast/child_8/flexy_beast_child_8.3mf
214.2 x 175.2 x 52.3 mm

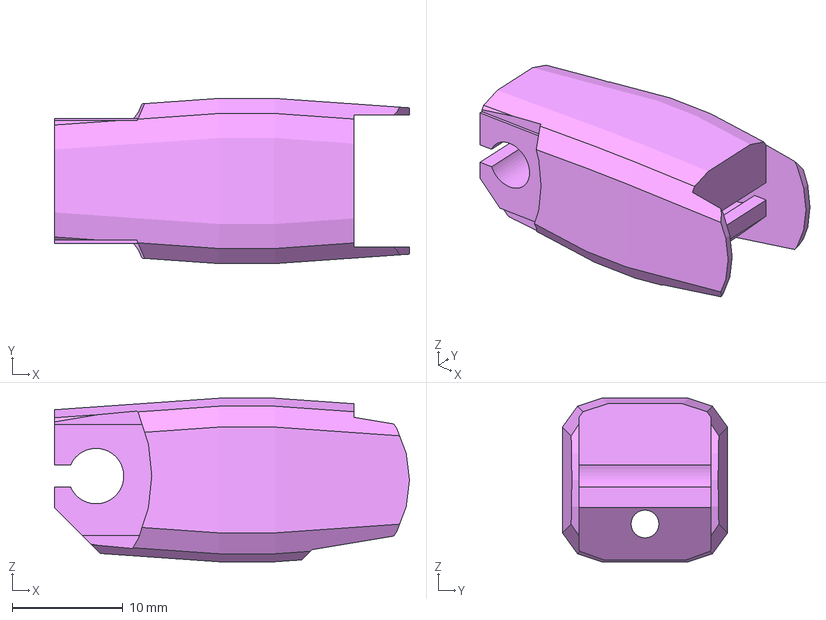
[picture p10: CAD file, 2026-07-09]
docs/print-validation/flexy_beast/child_8/parts/thumb_base.3mf
32.0 x 14.9 x 14.8 mm

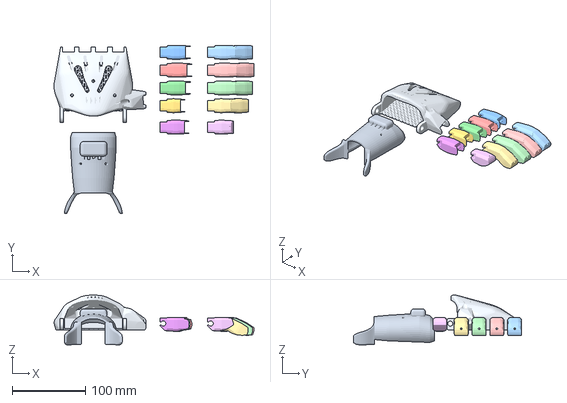
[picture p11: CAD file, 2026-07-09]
docs/print-validation/flexy_beast/elderly_70/flexy_beast_elderly_70.3mf
272.5 x 229.6 x 67.9 mm

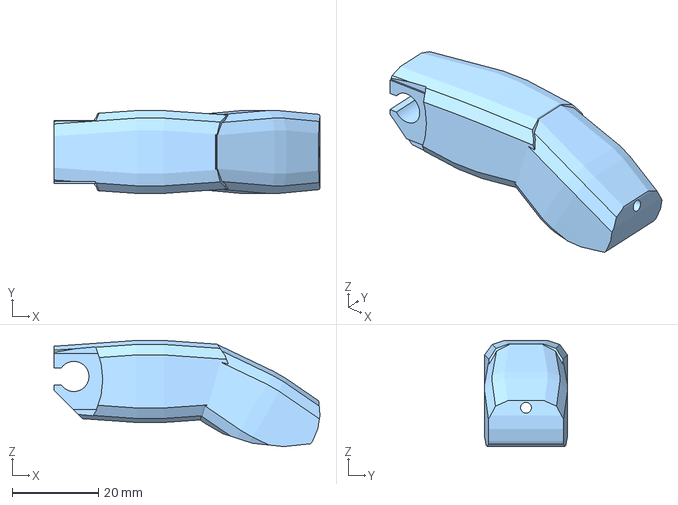
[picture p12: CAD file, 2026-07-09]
docs/print-validation/flexy_beast/elderly_70/parts/index_tip.3mf
61.8 x 19.2 x 24.6 mm

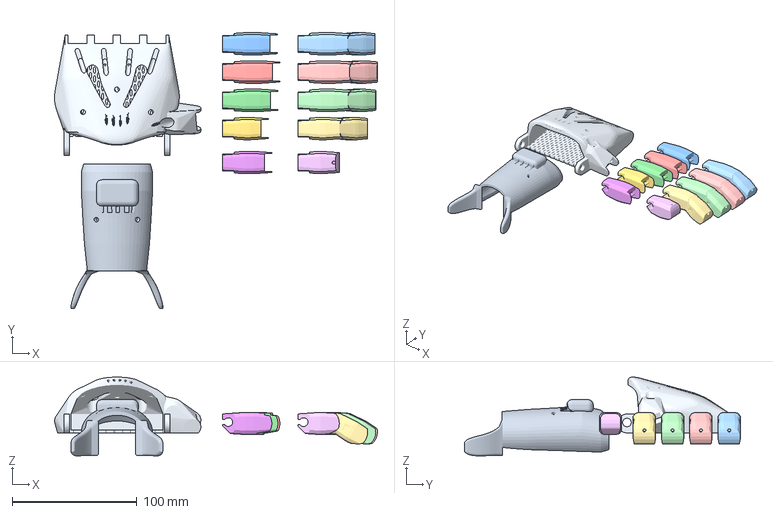
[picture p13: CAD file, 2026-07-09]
docs/print-validation/flexy_beast/teen_15/flexy_beast_teen_15.3mf
258.6 x 220.8 x 63.1 mm

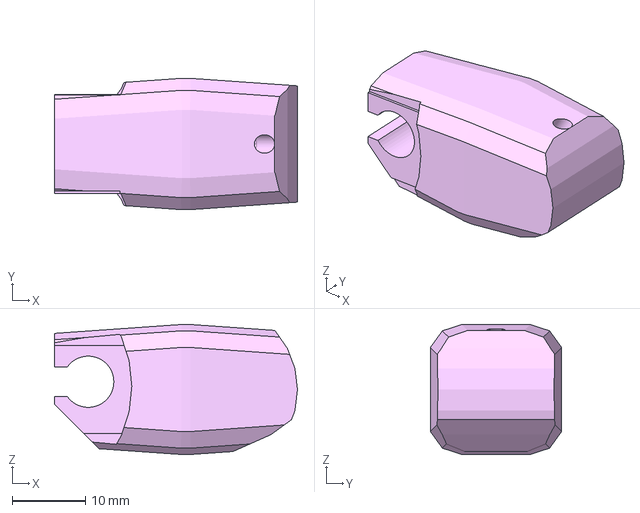
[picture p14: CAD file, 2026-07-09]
docs/print-validation/flexy_beast/teen_15/parts/thumb_tip.3mf
33.2 x 17.9 x 17.8 mm

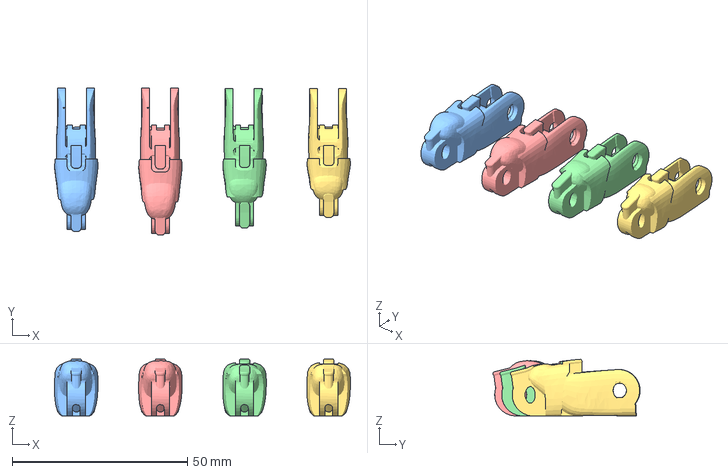
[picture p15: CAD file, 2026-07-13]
docs/print-validation/growth-series/unlimbed_phoenix_hand/age_08/parts/fingers.3mf
84.5 x 42.1 x 16.2 mm

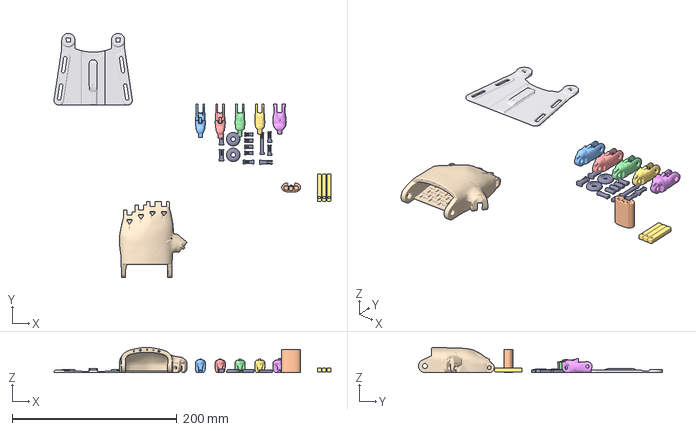
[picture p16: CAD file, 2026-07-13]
docs/print-validation/growth-series/unlimbed_phoenix_hand/age_08/unlimbed_phoenix_hand_age_08.3mf
335.8 x 296.0 x 30.6 mm

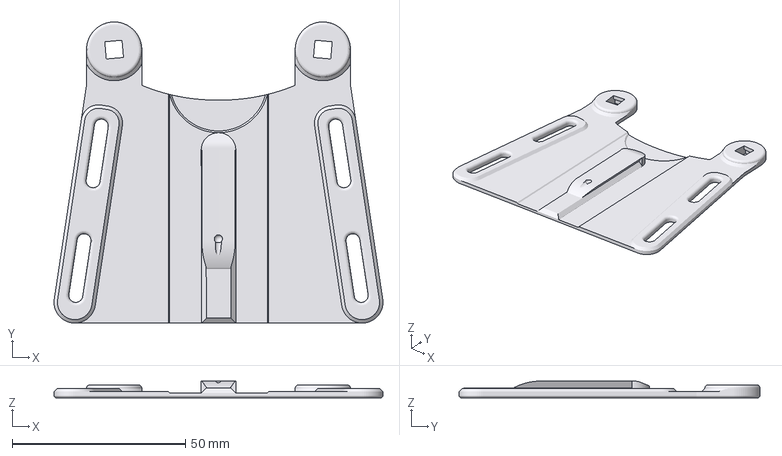
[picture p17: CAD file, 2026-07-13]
docs/print-validation/growth-series/unlimbed_phoenix_hand/age_12/parts/gauntlet.3mf
95.0 x 87.0 x 4.89 mm

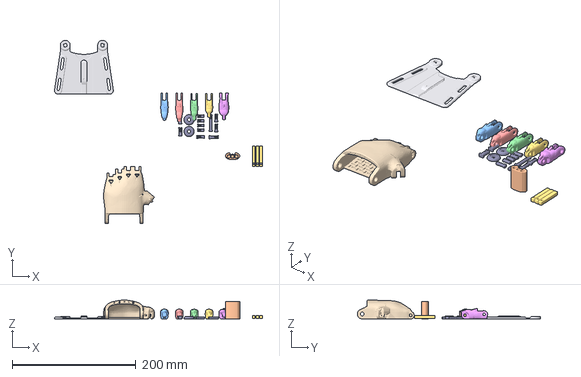
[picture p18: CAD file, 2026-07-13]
docs/print-validation/growth-series/unlimbed_phoenix_hand/age_12/unlimbed_phoenix_hand_age_12.3mf
335.8 x 296.0 x 30.6 mm

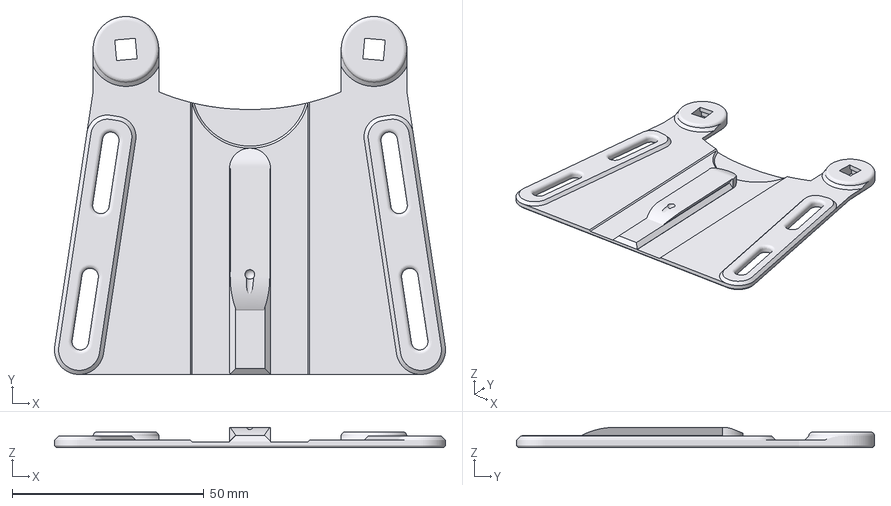
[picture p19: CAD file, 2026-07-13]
docs/print-validation/growth-series/unlimbed_phoenix_hand/age_15/parts/gauntlet.3mf
102.0 x 93.4 x 5.25 mm

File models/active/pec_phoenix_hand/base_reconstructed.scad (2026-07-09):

// Hybrid refinement of the optimizer result.
// This version preserves the optimizer shell and only expands the back plate
// envelope enough to better match the measured width and height.
plate_width = 24.8;
plate_height = 50.0;
plate_thickness = 3.0;

frame_depth = 14.957;
frame_outer_width = 12.8;
frame_outer_height = 27.4;
frame_back_width = 13.9;
frame_back_height = 29.8;
frame_inner_front_width = 9.7;
frame_inner_front_height = 25.2;
frame_inner_back_width = 9.75;
frame_inner_back_height = 24.4;

lug_center_z = 20.15;
lug_outer_radius = 4.85;
lug_hole_radius = 2.15;

show_reference = false;
reference_offset_x = 32.0;

$fn = 64;

module back_plate_profile() {
    hull() {
        translate([0, lug_center_z]) circle(r = lug_outer_radius);
        translate([0, -lug_center_z]) circle(r = lug_outer_radius);
        translate([plate_width / 2 - 1, 0]) circle(r = 1);
        translate([-plate_width / 2 + 1, 0]) circle(r = 1);
    }
}

module back_plate() {
    translate([0, -plate_thickness, 0])
        rotate([-90, 0, 0])
            linear_extrude(height = plate_thickness)
                back_plate_profile();
}

module front_frame_shell() {
    hull() {
        translate([-frame_outer_width / 2, -frame_depth, -frame_outer_height / 2])
            cube([frame_outer_width, 0.02, frame_outer_height]);
        translate([-frame_back_width / 2, -plate_thickness, -frame_back_height / 2])
            cube([frame_back_width, 0.01, frame_back_height]);
    }
}

module front_opening_cut() {
    hull() {
        translate([-frame_inner_front_width / 2, -frame_depth - 1.0, -frame_inner_front_height / 2])
            cube([frame_inner_front_width, 0.01, frame_inner_front_height]);
        translate([-frame_inner_back_width / 2, 1.0, -frame_inner_back_height / 2])
            cube([frame_inner_back_width, 0.01, frame_inner_back_height]);
    }
}

module lug_hole(z_pos) {
    translate([0, -frame_depth - 1, z_pos])
        rotate([-90, 0, 0])
            cylinder(h = frame_depth + plate_thickness + 2, r = lug_hole_radius);
}

module reconstructed_part() {
    difference() {
        union() {
            back_plate();
            front_frame_shell();
        }
        front_opening_cut();
        lug_hole(lug_center_z);
        lug_hole(-lug_center_z);
    }
}

module original_reference() {
    import("../../../../base.stl");
}

reconstructed_part();

if (show_reference) {
    color([0.2, 0.6, 0.9, 0.45])
        translate([reference_offset_x, 0, 0])
            original_reference();
}

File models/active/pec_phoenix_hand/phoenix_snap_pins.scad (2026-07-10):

// ====================================================================
// Snap_Pins — step2scad parametric reconstruction
// source: models/phoenix_components/Snap_Pins.step
// Every dimension is measured from the STEP B-rep (exact faces) or a
// fitted law with its residual cited — see the source comment on each
// parameter. Edit named parameters; geometry follows.
// ====================================================================

// --- Display options ---
show_colors   = false;   // tint top-level features (preview aid) — off so the assembly can recolour the pins
show_original = false;   // ghost the original tessellation overlay
original_stl  = "Snap_Pins_ref.stl";
module tint(c) { if (show_colors) color(c) children(); else children(); }

// --------------------------------------------------------------------
// BODY 0 — semantic parametric plan
//   semantic parametric pin: measured station circles segmented into
//   named plateau cylinders (exact faces where they agree) +
//   transition frustums; head stations and cutters vectorized;
//   engraved digit labels excluded by design — hull-loft along y from
//   measured sections; plan-view concavity cutters (fork slot/barb
//   notches); engraved label grooves (
// --------------------------------------------------------------------

// ======== PARAMETERS (every value measured; sources cited) ========
// --- b0 ---
b0_axis_x   = 27.792511;  // pin axis position (median of measured station centers, std < 0.001)
b0_axis_z   = 2.430429;  // pin axis height (median of measured station centers)
b0_tip_r    = 2.609331;  // plateau of 1 measured station circles (r spread < 0.012)
b0_tip_s0   = -16.535;  // measured plateau start along the pin axis
b0_tip_s1   = -16.535;  // measured plateau end along the pin axis
b0_seg1_r   = 2.79763;  // plateau of 1 measured station circles (r spread < 0.012)
b0_seg1_s0  = -16.345;  // measured plateau start along the pin axis
b0_seg1_s1  = -16.345;  // measured plateau end along the pin axis
b0_barb_r   = 3;  // EXACT cylinder face #16 (r=3.0)
b0_barb_s0  = -15.945;  // measured plateau start along the pin axis
b0_barb_s1  = -15.545;  // measured plateau end along the pin axis
b0_shaft_r  = 2.5;  // EXACT cylinder face #14 (r=2.5)
b0_shaft_s0 = -15.145;  // measured plateau start along the pin axis
b0_shaft_s1 = -5.145;  // measured plateau end along the pin axis
b0_flat_z0  = 0.530304;  // EXACT plane face (bottom flat) — pin sections are circles clipped by z flats
b0_flat_z1  = 4.9305;  // EXACT plane face (top flat)
b0_fn       = 96;  // curve resolution

module body_0() {
    difference() {
        intersection() {
            union() {
                // b0_tip_blend: measured transition between adjacent station plateaus (frustum)
                translate([b0_axis_x, b0_tip_s1, b0_axis_z]) rotate([-90, 0, 0]) cylinder(h=(b0_seg1_s0) - (b0_tip_s1), r1=b0_tip_r, r2=b0_seg1_r, $fn=b0_fn);
                // b0_seg1_blend: measured transition between adjacent station plateaus (frustum)
                translate([b0_axis_x, b0_seg1_s1, b0_axis_z]) rotate([-90, 0, 0]) cylinder(h=(b0_barb_s0) - (b0_seg1_s1), r1=b0_seg1_r, r2=b0_barb_r, $fn=b0_fn);
                // b0_barb: EXACT cylinder face #16 (r=3.0)
                translate([b0_axis_x, b0_barb_s0, b0_axis_z]) rotate([-90, 0, 0]) cylinder(h=(b0_barb_s1) - (b0_barb_s0), r=b0_barb_r, $fn=b0_fn);
                // b0_barb_blend: measured transition between adjacent station plateaus (frustum)
                translate([b0_axis_x, b0_barb_s1, b0_axis_z]) rotate([-90, 0, 0]) cylinder(h=(b0_shaft_s0) - (b0_barb_s1), r1=b0_barb_r, r2=b0_shaft_r, $fn=b0_fn);
                // b0_shaft: EXACT cylinder face #14 (r=2.5)
                translate([b0_axis_x, b0_shaft_s0, b0_axis_z]) rotate([-90, 0, 0]) cylinder(h=(b0_shaft_s1) - (b0_shaft_s0), r=b0_shaft_r, $fn=b0_fn);
                // b0_head_plate_0: head plate: constant axis-aligned rectangular section 4.40 x 6.75 over 6 measured stations (identical within 0.05; control-slice interp err <= 0.05) — measured section convex hull at y=-4.745 (high-res tessellation)
                translate([24.41751, -4.745, 0.5303]) cube([6.75, 1.86, 4.4002]);
                hull() {
                    // b0_head_0bridge: head station (vectorized: 4 lines + 0 arcs) — measured section convex hull at y=-4.745 (high-res tessellation)
                    rotate([0, -90, -90]) translate([0, 0, -4.745]) linear_extrude(0.02) polygon(concat(
            [[4.9305, 24.41751]],
            [[4.9305, 31.16751]],
            [[0.5303, 31.16751]],
            [[0.5303, 24.41751]]));
                    // b0_shaft_bridge0_disc: thin disc at the plateau boundary (bridges head block to the chain)
                    translate([b0_axis_x, b0_shaft_s1, b0_axis_z]) rotate([-90, 0, 0]) cylinder(h=(b0_shaft_s1 + 0.02) - (b0_shaft_s1), r=b0_shaft_r, $fn=b0_fn);
                }
            }
            // b0_flat_slab: z-slab between the EXACT plane flats (vertex circle-fits cannot see flats: all vertices lie on the circle)
            translate([15.792511, -28.535, b0_flat_z0]) cube([24, 35.39, b0_flat_z1 - b0_flat_z0]);
        }
        // b0_pocket0: vectorized cutter (5 lines + 0 arcs; capsule fit rejected, res 0.23-0.41) — plan-view concavity (silhouette hull minus measured outline at z=2.730402): fork slot / barb notch, vertical walls
        translate([0, 0, 0.030304]) linear_extrude(5.400196) polygon(concat(
            [[25.327997, -15.344508]],
            [[24.823364, -15.359508]],
            [[24.808624, -16.109506]],
            [[24.40252, -4.845029]],
            [[25.327997, -4.844508]]));
        // b0_pocket1: vectorized cutter (6 lines + 0 arcs; capsule fit rejected, res 0.23-0.41) — plan-view concavity (silhouette hull minus measured outline at z=2.730402): fork slot / barb notch, vertical walls
        translate([0, 0, 0.030304]) linear_extrude(5.400196) polygon(concat(
            [[31.182479, -4.843524]],
            [[30.791649, -16.095029]],
            [[30.761658, -16.094508]],
            [[30.761658, -15.359508]],
            [[30.257024, -15.344508]],
            [[30.272024, -4.829508]]));
        // b0_pocket2: vectorized cutter (8 lines + 0 arcs; capsule fit rejected, res 0.23-0.41) — plan-view concavity (silhouette hull minus measured outline at z=2.730402): fork slot / barb notch, vertical walls
        translate([0, 0, 0.030304]) linear_extrude(5.400196) polygon(concat(
            [[27.027511, -16.579508]],
            [[27.027799, -9.591582]],
            [[28.548251, -9.58065]],
            [[28.557511, -16.579508]],
            [[30.272024, -16.579508]],
            [[30.285883, -16.600248]],
            [[25.358402, -16.609508]],
            [[25.358402, -16.579508]]));
    }
}

// --------------------------------------------------------------------
// BODY 1 — semantic parametric plan
//   semantic parametric pin: measured station circles segmented into
//   named plateau cylinders (exact faces where they agree) +
//   transition frustums; head stations and cutters vectorized;
//   engraved digit labels excluded by design — hull-loft along x from
//   measured sections; plan-view concavity cutters (fork slot/barb
//   notches); engraved label grooves (
// --------------------------------------------------------------------

// ======== PARAMETERS (every value measured; sources cited) ========
// --- b1 ---
b1_axis_y    = 5.650405;  // pin axis position (median of measured station centers, std < 0.001)
b1_axis_z    = 2.033255;  // pin axis height (median of measured station centers)
b1_shaft_r   = 2;  // EXACT cylinder face #32 (r=2.0)
b1_shaft_s0  = -7.612;  // measured plateau start along the pin axis
b1_shaft_s1  = -0.012;  // measured plateau end along the pin axis
b1_seg1_r    = 2.280821;  // plateau of 1 measured station circles (r spread < 0.012)
b1_seg1_s0   = 0.388;  // measured plateau start along the pin axis
b1_seg1_s1   = 0.388;  // measured plateau end along the pin axis
b1_barb_r    = 2.362499;  // plateau of 2 measured station circles (r spread < 0.012)
b1_barb_s0   = 0.788;  // measured plateau start along the pin axis
b1_barb_s1   = 1.188;  // measured plateau end along the pin axis
b1_seg3_r    = 2.352554;  // plateau of 1 measured station circles (r spread < 0.012)
b1_seg3_s0   = 1.588;  // measured plateau start along the pin axis
b1_seg3_s1   = 1.588;  // measured plateau end along the pin axis
b1_collar_r  = 2.264702;  // plateau of 1 measured station circles (r spread < 0.012)
b1_collar_s0 = 1.748;  // measured plateau start along the pin axis
b1_collar_s1 = 1.748;  // measured plateau end along the pin axis
b1_flat_z0   = 0.530304;  // EXACT plane face (bottom flat) — pin sections are circles clipped by z flats
b1_flat_z1   = 3.733424;  // EXACT plane face (top flat)
b1_fn        = 96;  // curve resolution
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

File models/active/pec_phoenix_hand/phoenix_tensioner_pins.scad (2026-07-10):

// ====================================================================
// Tensioner_Pins — step2scad parametric reconstruction
// source: models/phoenix_components/Tensioner_Pins.step
// Every dimension is measured from the STEP B-rep (exact faces) or a
// fitted law with its residual cited — see the source comment on each
// parameter. Edit named parameters; geometry follows.
// ====================================================================

// --- Display options ---
show_colors   = false;    // tint top-level features (preview aid)
show_original = false;   // ghost the original tessellation overlay
original_stl  = "Tensioner_Pins_ref.stl";
module tint(c) { if (show_colors) color(c) children(); else children(); }

// --------------------------------------------------------------------
// BODY 0 — semantic parametric plan
//   fully parametric: expression octagons over exact plane dims; slot
//   walls as fitted arcs (res 0.036/0.005); exact bore. IoU 0.9987 vs
//   v1 0.9991 (parametric cost -0.0004)
// Anatomy (modules):
//   b0_hex_bar() — chamfered bar = intersection of three octagonal prisms whose...
//   b0_tendon_slot() — curved tendon slot between the two bspline walls — both walls are...
// --------------------------------------------------------------------

// ======== PARAMETERS (every value measured; sources cited) ========
// --- b0 ---
b0_bar_hw       = 2.377583;  // exact wall planes #0/#31 (x = ±bar_hw)
b0_bar_z0       = 0.659863;  // exact bottom plane #24
b0_bar_z1       = 5.413925;  // exact top plane #15
b0_bar_y_end    = 16.559241;  // exact end planes #16/#23 (y = ±bar_y_end)
b0_cham_xz      = 0.278416;  // exact 45° long-edge chamfer width (cone of planes #13/#25/#14/#30; top height differs by 0.0014)
b0_cham_top_h   = 0.277311;  // exact top chamfer axial height (planes #14/#30)
b0_end_cham     = 0.44193;  // exact 45° end/corner chamfer width (planes #4/#7/#26/#28 + #17/#18/#20/#21; equal within 2e-3)
b0_slot_hw      = 1.455185;  // exact slot wall planes #9/#10 (x = ±slot_hw)
b0_slot_head_cy = -16.167652;  // fitted arc center of the head-side slot wall (15 raycast samples, res 0.036)
b0_slot_head_cz = 3.146764;  // same fit
b0_slot_head_r  = 3.012252;  // same fit
b0_slot_bar_cy  = -16.102972;  // fitted arc center of the bar-side slot wall (15 raycast samples, res 0.005)
b0_slot_bar_cz  = 3.156136;  // same fit
b0_slot_bar_r   = 5.980054;  // same fit
b0_bore_r       = 1.507237;  // exact bore cylinder face #2
b0_bore_y_cap   = -8.770356;  // exact blind-end cap plane #1
b0_bore_z       = 3.037447;  // exact bore axis height (face #2)
b0_pin_pitch    = 5.8765;  // exact centroid delta between adjacent pins
b0_fn           = 96;  // curve resolution

// chamfered bar = intersection of three octagonal prisms whose vertices are EXPRESSIONS over the exact plane dimensions (change bar_hw / cham_xz / end_cham and the whole bar follows)
module b0_hex_bar() {
    intersection() {
        // b0_xsec: XZ octagon: exact wall/top/bottom planes + 45° chamfers
        rotate([0, -90, -90]) translate([0, 0, -b0_bar_y_end]) linear_extrude((b0_bar_y_end) - (-b0_bar_y_end)) polygon([[b0_bar_z0, b0_bar_hw - b0_cham_xz], [b0_bar_z0 + b0_cham_xz, b0_bar_hw], [b0_bar_z1 - b0_cham_top_h, b0_bar_hw], [b0_bar_z1, b0_bar_hw - b0_cham_xz], [b0_bar_z1, -(b0_bar_hw - b0_cham_xz)], [b0_bar_z1 - b0_cham_top_h, -b0_bar_hw], [b0_bar_z0 + b0_cham_xz, -b0_bar_hw], [b0_bar_z0, -(b0_bar_hw - b0_cham_xz)]]);
        // b0_plan_xy: XY octagon: exact walls/ends + 45° corner chamfers
        translate([0, 0, b0_bar_z0 - 0.5]) linear_extrude((b0_bar_z1 + 0.5) - (b0_bar_z0 - 0.5)) polygon([[b0_bar_hw, b0_bar_y_end - b0_end_cham], [b0_bar_hw - b0_end_cham, b0_bar_y_end], [-(b0_bar_hw - b0_end_cham), b0_bar_y_end], [-b0_bar_hw, b0_bar_y_end - b0_end_cham], [-b0_bar_hw, -(b0_bar_y_end - b0_end_cham)], [-(b0_bar_hw - b0_end_cham), -b0_bar_y_end], [b0_bar_hw - b0_end_cham, -b0_bar_y_end], [b0_bar_hw, -(b0_bar_y_end - b0_end_cham)]]);
        // b0_side_yz: YZ octagon: exact ends/top/bottom + 45° end chamfers
        rotate([90, 0, 90]) translate([0, 0, -b0_bar_hw - 0.5]) linear_extrude((b0_bar_hw + 0.5) - (-b0_bar_hw - 0.5)) polygon([[b0_bar_y_end - b0_end_cham, b0_bar_z0], [b0_bar_y_end, b0_bar_z0 + b0_end_cham], [b0_bar_y_end, b0_bar_z1 - b0_end_cham], [b0_bar_y_end - b0_end_cham, b0_bar_z1], [-(b0_bar_y_end - b0_end_cham), b0_bar_z1], [-b0_bar_y_end, b0_bar_z1 - b0_end_cham], [-b0_bar_y_end, b0_bar_z0 + b0_end_cham], [-(b0_bar_y_end - b0_end_cham), b0_bar_z0]]);
    }
}

// curved tendon slot between the two bspline walls — both walls are circular ARCS (fit residuals in the params), near-concentric around the tendon bend center; cut spans the exact slot wall planes in x
module b0_tendon_slot() {
    // b0_slot_cut: slot profile: two fitted wall arcs swept between declared z overshoots 0.40/5.70
    rotate([90, 0, 90]) translate([0, 0, -b0_slot_hw]) linear_extrude((b0_slot_hw) - (-b0_slot_hw)) polygon(concat(
            [for (k = [1 : 16]) [(b0_slot_head_cy) + (b0_slot_head_r)*cos((-65.76421) + k*((57.95342) - (-65.76421))/16), (b0_slot_head_cz) + (b0_slot_head_r)*sin((-65.76421) + k*((57.95342) - (-65.76421))/16)]],
            [for (k = [1 : 16]) [(b0_slot_bar_cy) + (b0_slot_bar_r)*cos((25.175441) + k*((-27.444433) - (25.175441))/16), (b0_slot_bar_cz) + (b0_slot_bar_r)*sin((25.175441) + k*((-27.444433) - (25.175441))/16)]]));
}

module tpins_body_0() {
    difference() {
        b0_hex_bar();  // b0_bar_i
        b0_tendon_slot();  // b0_slot_i
        // b0_tendon_bore: blind tendon bore: exact cylinder face #2 + cap plane #1; +y end overshoots the exit by 1
        translate([0, b0_bore_y_cap, b0_bore_z]) rotate([-90, 0, 0]) cylinder(h=(b0_bar_y_end + 1) - (b0_bore_y_cap), r=b0_bore_r, $fn=b0_fn);
    }
}

// ---- body 1 (strategy: instance_of body 0 — agent plan) ----
b1_offset = [5.8765, 0, 0];  // exact centroid delta (= pin_pitch param)

module tpins_body_1() {
    translate(b1_offset) tpins_body_0();
}

// ---- body 2 (strategy: instance_of body 0 — agent plan) ----
b2_offset = [-5.8765, 0, 0];  // exact centroid delta (= -pin_pitch)

module tpins_body_2() {
    translate(b2_offset) tpins_body_0();
}


// ---- assembly helper: all three flat tensioner pins, centred on XY origin ----
module tensioner_pins_centered(){ tpins_body_0(); tpins_body_1(); tpins_body_2(); }

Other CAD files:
docs/print-validation/growth-series/unlimbed_phoenix_hand/age_15/unlimbed_phoenix_hand_age_15.3mf
docs/print-validation/growth-series/unlimbed_phoenix_hand/age_18/parts/gauntlet.3mf
docs/print-validation/growth-series/unlimbed_phoenix_hand/age_18/unlimbed_phoenix_hand_age_18.3mf
docs/print-validation/paraglider_hand/adult_28/paraglider_hand_adult_28.3mf
models/active/pec_phoenix_hand/reborn-wrist-pin-cap_reconstructed.scad
archive/cyborg-beast/cyborgbeast07l.scad
docs/print-validation/flexy_beast/adult_28/parts/gauntlet.3mf
docs/print-validation/flexy_beast/adult_28/parts/index_tip.3mf
docs/print-validation/flexy_beast/adult_28/parts/middle_base.3mf
docs/print-validation/flexy_beast/adult_28/parts/middle_tip.3mf
docs/print-validation/flexy_beast/adult_28/parts/palm.3mf
docs/print-validation/flexy_beast/adult_28/parts/pinky_base.3mf
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

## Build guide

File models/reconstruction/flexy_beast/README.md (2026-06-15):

# Flexy Beast — Gauntlet reconstruction (dev-only)

Source files and variants from reverse-engineering the forearm gauntlet. **None of
these are used by the platform** — they are excluded from deploy. The platform model
is `models/active/flexy_beast/flexy_beast.scad`, which already contains the finished
(primitive) gauntlet inlined.

| File | What it is |
|---|---|
| `Normal_Gauntlet_w_Tensioner.stl` | Original source mesh that was reconstructed |
| `normal_gauntlet_w_tensioner.scad` | Organic reconstruction (lofts mesh-extracted wall profiles via BOSL2 `skin`) — needs `gauntlet_profiles.scad` + `gauntlet_straps.scad`. **Requires BOSL2** (not WASM-safe) |
| `gauntlet_profiles.scad` | Extracted cuff wall cross-sections (data) for the organic variant |
| `gauntlet_straps.scad` | Extracted strap station data |
| `normal_gauntlet_w_tensioner_primitive.scad` | Primitive rebuild — tapered oval half-pipe tunnel + features. No BOSL2 (OpenSCAD-WASM-safe). This is the version that was merged into `flexy_beast.scad` |
| `normal_gauntlet_w_tensioner_reconstructed.stl` | Exported organic reconstruction |
| `output/`, `previews/` | Build artifacts (regenerate on render) |

Coordinate frame (all variants): X = width, Y = forearm axis (+Y = wrist/proximal),
Z = dorsal up. ~75% geometric accuracy (organic) / volume within ~0.5% (primitive).

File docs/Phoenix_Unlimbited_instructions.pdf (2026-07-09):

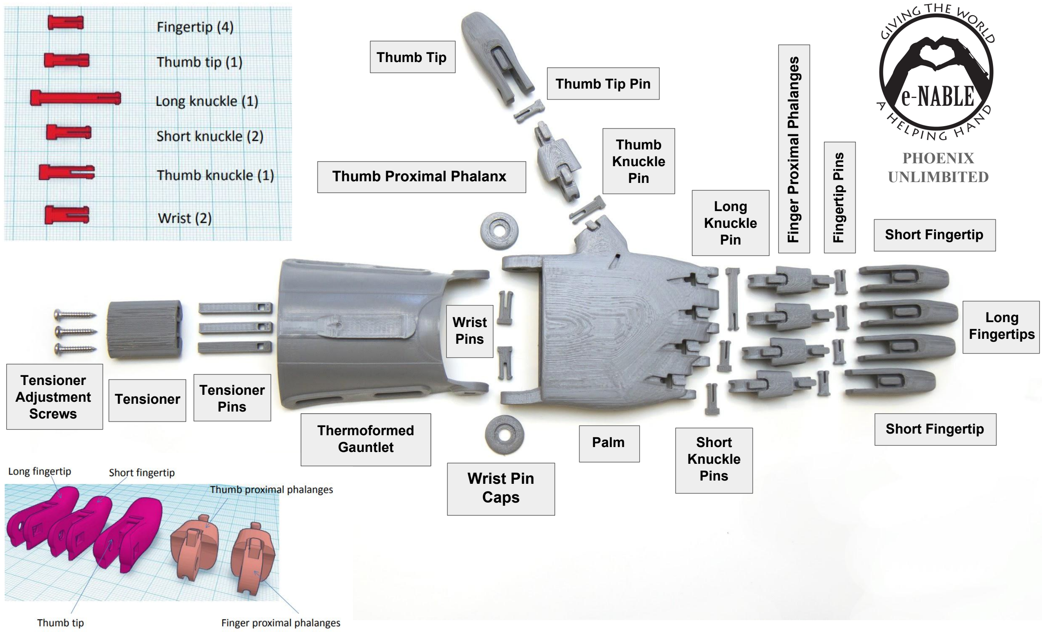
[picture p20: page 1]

Wrist
Pins

Wrist Pin
Caps

Tensioner
Adjustment
Screws

Tensioner Tensioner Pins

Short
Knuckle
Pins

Long
Knuckle
Pin

Finger Proximal Phalanges

Fingertip Pins

Short Fingertip

Thumb Tip

Thumb Proximal Phalanx

Short Fingertip

Long
Fingertips

Thumb Tip Pin

Thumb
Knuckle
Pin

Palm

Thermoformed
Gauntlet

PHOENIX
UNLIMBITED

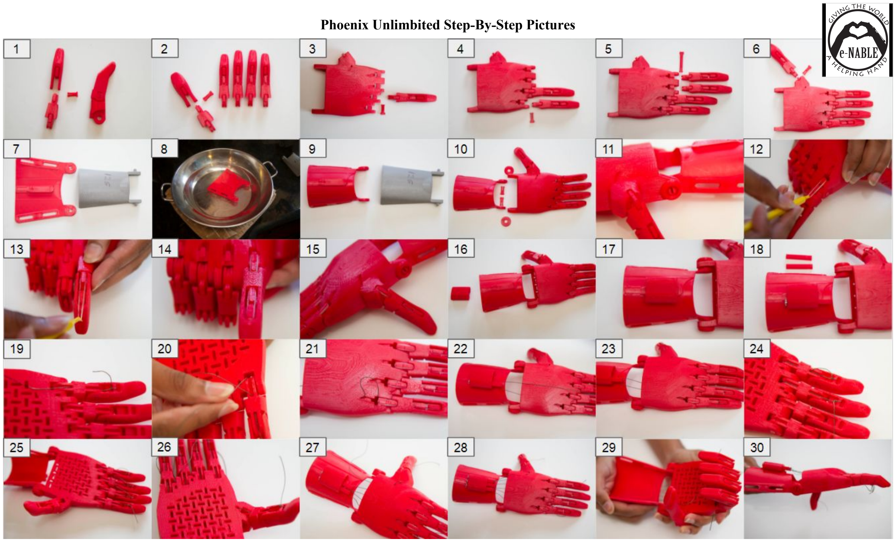
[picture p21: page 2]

Phoenix Unlimbited Step-By-Step Pictures

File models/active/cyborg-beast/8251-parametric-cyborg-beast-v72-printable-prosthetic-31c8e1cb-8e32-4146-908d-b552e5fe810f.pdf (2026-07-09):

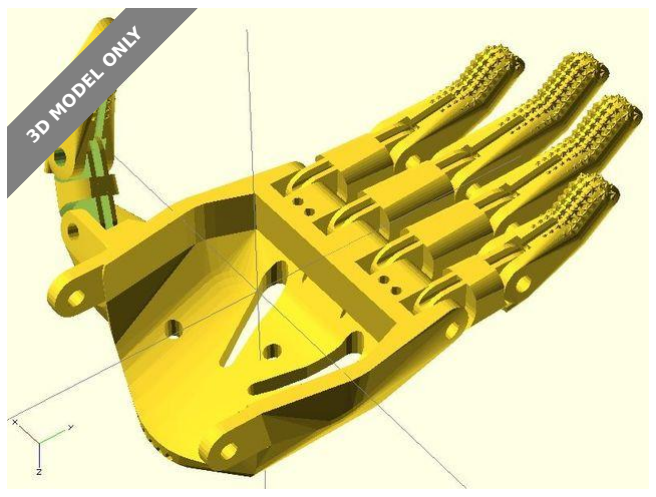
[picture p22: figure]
3D MODEL ONLY

# Summary

Now with fingers! Please see the original Cyborg Beast for assembly

instructions.

Healthcare (https://www.printables.com/model?categoryId=87) | > | Home Medical Tools (https://www.printables.com/model?categoryId=88)
Tags: enable | cyborgbeast | diyprosthetics | prosthetic

prosthetics

Now with fingers!

Please see the original Cyborg Beast for assembly instructions. http://

www.thingiverse.com/thing:261462

The finger modules allow customization of the finger length, scale, and

whether there are finger bumps. The thumb shown is a slightly shorter

finger. I plan to design a separate thumb.

## Print instructions

Category: People

MakerBlock (https://www.printables.com/social/34150/about)

# Parametric Cyborg Beast v7.2 (Printable Prosthetic)

VIEW IN BROWSER (https://www.printables.com/model/8251-parametric-cyborg-beast-v72-printable-prosthetic)

updated 12. 4. 2022 | published 10. 2. 2022

# Model files

Find source .stl files on Thingiverse.com (https://www.thingiverse.com/thing:320173)

# License

This work is licensed under a

Creative Commons (4.0 International License)

Attribution-NonCommercial (http://creativecommons.org/licenses/by-nc/4.0/)

✖ | Sharing without ATTRIBUTION
✔ | Remix Culture allowed
✖ | Commercial Use
✖ | Free Cultural Works
✖ | Meets Open Definition

cyborgbeast07l.scad

cyborgpalm001.scad

cyborgfingertip002.scad

cyborgfingermid002.scad

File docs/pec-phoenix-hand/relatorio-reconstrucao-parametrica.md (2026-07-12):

# Reconstrução paramétrica da mão protésica e-NABLE Phoenix (modelo *pec Phoenix hand*)

**Relatório técnico de desenvolvimento** — 12 de julho de 2026 (desenvolvimento decorrido a 11–12 de julho de 2026)
Repositório: `ai-parametric-prosthetic-hand-generator` · modelo `models/active/pec_phoenix_hand/` · versões v14.51.0–v14.56.0 do registo de alterações (`CHANGELOG.md`)

---

## 1. Introdução e objetivos

As próteses de mão de fabrico aditivo distribuídas pela comunidade e-NABLE — em particular a família Phoenix/UnLimbited — circulam maioritariamente sob a forma de malhas triangulares (STL), resultado de processos de modelação escultórica. Este formato, adequado à impressão direta, é inadequado à personalização antropométrica: uma malha não expõe dimensões com significado clínico (largura da palma, comprimento das falanges, diâmetros de furação), pelo que qualquer ajuste ao paciente se reduz a uma escala global uniforme, com as distorções funcionais conhecidas (folgas de pinos e canais que escalam juntamente com a anatomia).

O presente trabalho documenta a reconstrução da palma esquerda e das falanges da mão Phoenix como **modelos paramétricos legíveis em OpenSCAD**, integráveis na plataforma de geração de próteses desenvolvida no âmbito desta dissertação. Os objetivos específicos foram:

1. **Fidelidade dimensional** às peças originais, com as interfaces funcionais (furos de pinos, ranhuras, canais de cabo) dimensionalmente exatas;
2. **Parametrização com significado** — cada número editável deve corresponder a uma característica física identificável, com os valores medidos no original como *defaults*;
3. **Eliminação progressiva das dependências de malha** (recortes por interseção com o STL original), condição necessária à portabilidade para o renderizador OpenSCAD WebAssembly da plataforma, que não dispõe dos ficheiros STL locais;
4. **Verificabilidade** — instrumentação de verificação incorporada no próprio modelo e métricas quantitativas de semelhança geométrica.

## 2. Metodologia

Adotou-se o método de reconstrução por fidelidade de características documentado internamente em `openscad-parametric-reconstructor/RECONSTRUCTION_METHOD.md`, cujo princípio nuclear se resume na máxima *measure, never guess*: nenhuma dimensão entra no código sem provir de uma medição sobre a malha original. Os elementos essenciais do método são:

- **Malha-fantasma alinhada (*ghost*).** O STL original é realinhado ao referencial do modelo (centrado em X/Y, base em Z = 0) e importado de forma translúcida sobre a reconstrução, permitindo verificação visual contínua da coincidência de envelopes. No modelo da palma, o original apresenta uma caixa envolvente de X ±41,43 mm, Y ±46 mm e Z 0–30,6 mm.
- **Medição instrumentada.** Extração de perfis por secção (`stl-to-openscad.py`), mapas de ocupação (`mesh.contains`), varrimentos de secções e extração de faces originais por zona, com tabelas comparativas *alvo | obtido* a preceder qualquer alteração de código.
- **Construção por primitivas simples**, fundidas por `union()` e escavadas por `difference()`, privilegiando a legibilidade sobre a mimetização cega da malha.
- **Instrumentação de verificação no Customizer** do próprio ficheiro: sobreposição do *ghost* (`show_ghost`), planos de corte (`section` longitudinal/transversal/horizontal com `section_at`) que seccionam simultaneamente modelo e *ghost*, e vista colorida por peça (`debug_colors`).
- **Métrica quantitativa.** A semelhança volumétrica é avaliada por *Intersection over Union* (IoU) voxelizada (passo 0,4–0,5 mm; `verify_recon.py`), reportada de forma honesta e nunca usada como critério binário de aceitação — para cascas orgânicas finas, primitivas legíveis limitam estruturalmente o IoU atingível.
- **Verificação topológica.** Exportação STL com confirmação de variedade fechada (*manifold*, estado `NoError` no relatório do OpenSCAD).

A este método acrescentou-se, na fase aqui descrita, uma **análise comparativa de modelos abertos da comunidade e-NABLE** (Cyborg Beast, família *flexible flyer*/paraglider, gerador *fingerator*), com o propósito de identificar idiomas de construção paramétrica transferíveis. Sublinha-se que a transferência incide sobre **técnicas**, nunca sobre dimensões: copiar formas de uma família de mãos distinta degradaria a fidelidade ao original Phoenix.

## 3. Arquitetura do modelo

### 3.1 Ficheiro único com peças comutáveis

O modelo da palma foi consolidado num único ficheiro, `Palm_left_V2.scad` (v14.51.0), absorvendo os cinco ficheiros parciais anteriormente incluídos por `include`. O ficheiro organiza-se em sete secções (*PARTES*), cada uma com uma caixa de verificação própria no grupo `[Features]` do Customizer, permitindo isolar qualquer peça para inspeção, depuração ou impressão parcial:

| Parte | Conteúdo | Comutador |
|---|---|---|
| 1 | Casca dorsal (arco + canais de cabo) | `show_shell` |
| 2 | Montagem de pivô do polegar | `show_thumb` |
| 3 | Clevises de pivô dos dedos (nós) | `show_knuckles` |
| 4 | Aletas dorsais e coroas | `show_fins` |
| 5 | Orelhas de charneira e paredes do punho | `show_wrist` |
| 6 | Parede posterior do punho | `show_wrist_back` |
| 7 | Chão palmar perfurado | `show_grid` |

O módulo `model()` funde as peças ativas; os furos globais são recortados por peça, garantindo que cada comutador produz um sólido coerente (Figura 4).

### 3.2 Montagem

O ficheiro `_assembly.scad` compõe a mão completa: palma, falanges proximais e distais, guarda de antebraço e ferragens. Os pinos de encaixe e o bloco tensor provêm de reconstruções B-rep exatas a partir de ficheiros STEP (`phoenix_snap_pins.scad`, `phoenix_tensioner_block.scad`, `phoenix_tensioner_pins.scad`, v14.50.0), assentes nas interfaces medidas da palma (pinos dos nós, furo do polegar, orelhas do punho). Toda a alteração às peças propaga-se automaticamente à montagem, uma vez que esta inclui o ficheiro da palma e chama os módulos por nome (Figura 7).

## 4. Técnicas paramétricas adotadas

O núcleo do trabalho consistiu em substituir geometria de origem orgânica — tabelas de pontos medidos e recortes pela malha original — por construções paramétricas suaves, adotando idiomas identificados em modelos abertos da comunidade.

### 4.1 Casca dorsal: técnica *hull-of-primitives* (proveniência: Cyborg Beast)

A casca dorsal encontrava-se implementada como um *loft* (`skin()` da biblioteca BOSL2) de 30 estações transversais com 34 pontos cada — cerca de mil coordenadas medidas, regeneradas por um passo de ajuste automático e, por isso, não editáveis manualmente. Tratava-se de geometria *data-driven*: paramétrica na construção, mas orgânica na forma.

A análise do modelo Cyborg Beast (`cyborgpalm001.scad`, módulo `cyborgbeast07palm`) revelou o idioma alternativo: o sólido exterior é **um único `hull()` estendido sobre meia dúzia de primitivas de controlo com nome** (esferas achatadas por `scale`, cilindros, prismas finos), a cavidade interior é um segundo `hull()` de primitivas próprias, subtraído, e os cortes funcionais são aplicados no fim. O invólucro convexo estica uma "pele" G1-contínua sobre as primitivas, produzindo superfícies suaves sem tabelas de pontos.

A casca foi reconstruída segundo este idioma (v14.53.0): três **estações de controlo** (rebordo do punho, secção média, rebordo dos dedos), cada uma composta por um elipsoide de coroa achatado e dois postes de parede; o exterior é o `hull()` das três estações, cortado por planos verticais nos dois rebordos; a cavidade é o mesmo `hull()` com as estações encolhidas pela espessura de parede, prolongado para além dos rebordos e abaixo da placa, de modo a deixar o fundo e os topos abertos; os cinco canais de cabo são subtraídos no fim. O grupo `[Shell]` do Customizer expõe 18 parâmetros — espessura de parede (`SHELL_WALL` = 5,0 mm), raio dos canais (`CH_R` = 1,23 mm), altura do "joelho" parede/coroa (`SHELL_KNEE_Z` = 20 mm), três parâmetros de forma da coroa (`CROWN_FLAT/RZ/RY`) e doze escalares de estação (`Y`, `X` esquerdo, `X` direito e altura de ápice por estação) — todos com os valores medidos como *defaults*, pelo que a renderização por omissão continua a acompanhar o envelope original (Figuras 1–3).

A verificação incluiu sobreposição com o *ghost*, secções transversal, longitudinal e horizontal (parede uniforme de ~5 mm; canais embebidos no teto) e exportação STL da casca isolada com estado *manifold* `NoError`.

Numa iteração posterior (v14.56.0, 12 de julho de 2026) eliminou-se o vinco de ~90° na transição parede→coroa com a introdução do parâmetro `KNEE_R` (3,5 mm por omissão) no grupo `[Shell]`: um par de cilindros de concordância por estação, tangentes aos planos exteriores das paredes à altura do "joelho" (z = 20 mm), com cópia concêntrica na cavidade de raio `KNEE_R` menos a espessura de parede, o que preserva a espessura uniforme da casca ao longo da concordância (Figura 12). Após a alteração, o modelo completo manteve o estado *manifold* `NoError` e a montagem renderiza sem avisos.

### 4.2 Chão palmar: contorno por primitivas ancoradas (proveniência: `Palm_left_floor.scad`)

O chão perfurado assentava num polígono de 45 pontos medidos e, na banda frontal, num recorte por interseção com o STL original (*ghost-clip*), que conformava a placa à face inferior côncava sob os nós dos dedos.

Do ficheiro de referência `Palm_left_floor.scad` transferiu-se o idioma da **placa extrudida a partir de um contorno 2D suavizado por cadeias de `offset`**, levado mais longe: o contorno passou a ser a **união de primitivas de pegada com nome, cada uma ancorada à peça vizinha com que solda** — corpo principal sob os pés da casca, aventais e abas frontais por clevis de dedo (parando a `cy − folga` para preservar o curso de flexão do dedo), abas posteriores derivadas das estações das orelhas do punho e apoios do polegar alinhados com o eixo de 50° do respetivo pivô. A suavização aplica um fecho morfológico (filete côncavo) seguido de abertura (arredondamento convexo), com raios paramétricos de 1,2 mm. A grelha de ventilação em *basket-weave* manteve os seus nove parâmetros. O grupo `[Floor]` expõe dez parâmetros de contorno (espessura, sobreposição de soldadura, raios, alcances das abas, folgas), com as coordenadas antigas a sobreviver apenas como *defaults*.

O resultado eliminou por completo a dependência do *ghost* nesta peça, mantendo a cobertura das zonas de acoplamento (Figura 5). A verificação do modelo completo com o novo chão reportou *manifold* `NoError` (género topológico 124, ~83 000 facetas) e nenhum aviso novo de renderização.

### 4.3 Canais de cabo: perfil autoportante e escala inversa (proveniência: *flexible flyer*/paraglider)

A análise dos ficheiros `paraglider_palm_unlimbited_v3.scad`, `paraglider_palm_unlimbited_v3_tensor.scad` e `paraglider_palm_left_tensor.scad` (Marcus Mendenhall, família *flexible flyer*) concluiu que estes **não constroem a palma parametricamente** — importam uma malha base da própria família Phoenix e re-parametrizam apenas as interfaces (idioma *plug-then-drill*: tapar a característica cozida na malha com um sólido sobredimensionado e refurá-la parametricamente). O seu valor para o presente trabalho reside em três idiomas de interface:

1. **Secção em "D" autoportante para os canais de tendão** — fundo plano com cantos chanfrados e arco superior, varrida ao longo de percursos com curvas suavizadas, dispensando suportes de impressão no interior dos furos.
2. **Suavização dos percursos** por interpolação das dobras (equivalente BOSL2: `round_corners` sobre as polilinhas medidas dos cinco canais).
3. ***Inverse-scaling* das interfaces.** Quando o modelo é escalado globalmente para o tamanho do paciente, as dimensões do *hardware* físico (parafusos, pinos, cordel) não escalam. O idioma consiste em dividir cada dimensão de interface pelo fator de escala global antes da aplicação do `scale()` — por exemplo, `cylinder(d = 3.5/overall_scale)` para um furo de parafuso M3 —, de modo que a peça impressa apresente sempre a dimensão nominal do componente, independentemente da escala anatómica. Este princípio será adotado quando a palma receber o gancho de escala global da plataforma; previne a classe de defeitos de dimensionamento já observada noutros modelos do repositório.

Os dois primeiros idiomas foram implementados em `Palm_left_V2.scad`. O perfil "D" foi **invertido** relativamente ao paraglider — chão semicircular e teto quase plano com chanfros a 45° — dado que a palma Phoenix se imprime com o chão na plataforma, colocando o vão em consola no **teto** do furo. A suavização das dobras é feita por `round_corners` (método *smooth*), com raio paramétrico `CH_BEND_R` = 1,2 mm. Os pontos de passagem dos cinco canais, medidos sobre o teto orgânico antigo, foram re-ajustados para acompanhar a coroa paramétrica: os percursos permanecem embebidos na banda de teto de 5 mm até y ≈ 16–22 mm e mergulham depois a 30–45° para as saídas medidas junto aos clevises. Onde um canal abandona o material do teto, é envolvido por uma **bainha tubular impressa** (parede `CH_SHEATH_WALL` = 1,4 mm), ao estilo dos condutos exteriores do *flexible flyer*, de modo que o furo nunca fica exposto. Os cortes passaram a ser gerados por um único módulo, `cable_channels()`, partilhado pelos três locais que os subtraem (`dorsal_shell()`, `front_assembly()`, `wrist_back()`), o que garante o alinhamento exato entre re-cortes. A verificação por secções confirmou os cinco furos embebidos com o teto em "D"; o modelo completo renderiza sem erros e a casca isolada exporta *manifold* `NoError`.

### 4.4 Falanges: idiomas do *fingerator* e melhoria do IoU

Os modelos das falanges (`Proximals.scad`, `Distals_v2.scad`) foram avaliados quantitativamente contra as malhas originais alinhadas, estabelecendo o primeiro *baseline* medido:

| Peça | IoU | Volume excedente | Volume em falta | Observações |
|---|---|---|---|---|
| Falange proximal | 0,947–0,949 | 76 mm³ | 59 mm³ | erro concentrado nos flancos frontais e no rebaixo inferior |
| Falange distal (std) | 0,906–0,914 | 245 mm³ | 85 mm³ | rácio de volume 1,058; erro dominante nos "ombros" das secções |

A análise do gerador *fingerator* (mesma autoria da família *flexible flyer*; cópia local `fingerator.scad`) identificou a razão da suavidade das suas superfícies: **nenhum paralelepípedo aparece em superfície visível** — as secções do corpo são `hull()` de círculos escalados (ovais contínuos), a ponta é um único `hull()` de esferas achatadas e meio toro, as extremidades das forquilhas resultam de interseção com um cilindro concêntrico com o pino, e os relevos côncavos são cilindros elípticos inclinados subtraídos. Em contrapartida, a falange distal reconstruída usa retângulos arredondados nas secções do *loft*, que mantêm os cantos cheios onde o original apresenta secções ovais/ovoides — a origem dos ~118 mm³ excedentes na zona de flexão.

Foi definido e executado um plano de adaptação em seis pontos (P1–P6), aplicado sobre cópias de trabalho (`Distals_v3.scad`, `Proximals_v2.scad`; os ficheiros originais foram preservados como referência), com verificação IoU após cada alteração e preservação estrita das interfaces funcionais — furos e ranhuras de pinos, carris e, em particular, as **aletas dorsais**, características do desenho Phoenix e ausentes no *fingerator*. Alterações que degradaram a métrica foram revertidas (caso do *loft* do corpo cilíndrico da proximal, que regrediu para 0,963).

**Falange proximal** — IoU 0,949 → **0,965** (voxel de 0,4 mm; 0,962 a 0,5 mm), rácio de volume 1,002. Progressão por alteração: P5, afunilamento frontal em três estações (0,950); P6a, rebaixos inferiores elípticos, inclinados e assimétricos (0,958); P6b, barriga em *loft* de dois círculos medidos (0,961); P6c, pés inferiores quase planos por interseção elipse ∩ plano (0,964) — etapa que produziu um achado de medição: as paredes inferiores do original assentam em faces quase planares, com inclinações de 5,3° e 1,1°; P6d, reajuste analítico final (0,965). A invariância das interfaces foi confirmada por soma de verificação (*md5*) módulo a módulo: `pin_hole`, carris, discos dos nós e aletas com coroas permaneceram byte a byte idênticos.

**Falange distal** — IoU por variante: std 0,906 → **0,964**; short 0,908 → **0,962**; thumb 0,879 → **0,972**; rácios de volume 0,992, 0,989 e 0,997, respetivamente. Em P1, as secções do *loft* passaram de retângulos arredondados a perfis superelípticos com afunilamento ("ovo"), ajustados por mínimos quadrados estação a estação contra a malha original (resíduo RMS de 0,02–0,14 mm), mantendo fixa a contagem de vértices (96) para preservar a correspondência do `skin()`. P2 produziu o segundo achado de medição: a face de fundo da ranhura do pino do original **é um cilindro concêntrico com o furo do pino, de raio 7,39 mm, idêntico nos três tamanhos** — precisamente o idioma do *fingerator*, confirmado assim no próprio desenho Phoenix — complementado por dois rebaixos de entrada do furo, medidos. P3 densificou a cúpula da ponta com cinco a seis estações medidas (caixa envolvente Y = 43,52 mm contra 43,60 mm no original); P4 deu à goteira do tendão um fundo com inclinação medida por tamanho e uma rampa de saída do cordel. Os invariantes (ranhura de 5,90 mm, pino, vetores `feat_*`, aleta e coroa) mantiveram-se byte a byte idênticos e foram confirmados na geometria renderizada.

As Figuras 8–10 documentam a comparação visual de partida que motivou o plano.

### 4.5 Clevises dos dedos: eliminação do *ghost-clip* e costura paramétrica com a casca

Na iteração de 12 de julho de 2026 (v14.56.0), a Parte 3 — os quatro clevises de pivô dos dedos e a respetiva junção com a casca dorsal — tornou-se **totalmente paramétrica**, eliminando o operador `clip_ghost` que até aí aparava toda a peça pela malha original. A reconstrução seguiu o princípio de medição por característica: os olhos de pivô passaram a invólucros (`hull`) medidos **por prong físico**, mantendo exatos os discos-pé de raio 5,9 mm tangentes à placa e substituindo o anterior disco de sobre-enchimento aparado pela malha por topos de "capuz" medidos; as caixas de fusão posteriores (*backboxes*) deram lugar a pescoços e cortinas com dimensões medidas; e a banda de junção que era recortada pela malha foi substituída por lajes de flanco e de vão complementadas por bolsas de janela arredondadas, cujos postes de rebordo **seguem o perfil do rebordo da casca paramétrica**, produzindo uma costura C0 sem degrau — o efeito de "escada" anteriormente visível no canto do mindinho foi eliminado por interpolação entre os níveis dos dedos (Figuras 11 e 13). Os *keyholes* funcionais (furo redondo e ranhura retangular do pino) continuam a ser cortados no fim, com as dimensões byte-exatas; os canais de cabo são re-cortados pelo módulo partilhado `cable_channels()`, com enclausuramento melhorado (canal 1 a 96 %, canal 2 a 100 %) e as bocas verificadas abertas por *flood-fill* voxelizado.

Regista-se, por transparência metodológica, o custo desta escolha na métrica volumétrica: o IoU voxelizado da banda dos nós (Y 18–46 mm) desceu de 0,909 para 0,730. O volume excedente corresponde à **junção contínua com a casca, escolhida deliberadamente** segundo o critério de projeto definido pelo utilizador — suavidade da ligação à casca acima da fidelidade à malha bruta, que naquela zona exibia rebordos expostos com degraus até 5 mm. Trata-se, portanto, de um desvio documentado e parametrizado (a geometria de junção é afinável pelos parâmetros da costura), e não de uma regressão acidental — um exemplo concreto do enquadramento metodológico que reporta o IoU honestamente sem o erigir em critério binário de aceitação (secção 2).

## 5. Resultados e verificação

À data de 12 de julho de 2026, encontram-se concluídos e verificados:

- **Consolidação e comutadores por peça** (v14.51.0) — as sete peças isolam-se individualmente; a montagem completa renderiza sem erros.
- **Casca dorsal paramétrica** (v14.53.0) — sobreposição *ghost* com acompanhamento próximo do envelope (Figura 1); secções com parede uniforme de ~5 mm e canais embebidos (Figuras 2–3); STL isolado *manifold* `NoError`; soldadura preservada com clevises, polegar, punho e chão no modelo completo (Figura 6).
- **Chão palmar paramétrico** (v14.53.0) — contorno suave sem malha original; abas alinhadas sob os prongs dos clevises e apoios do polegar confirmados contra o *ghost* (Figura 5); modelo completo *manifold* `NoError`; montagem íntegra em vista inferior (Figura 7).
- **Canais de cabo em perfil "D"** — os cinco canais re-encaminhados e embebidos na coroa paramétrica, com teto autoportante, dobras suavizadas e bainhas tubulares onde saem do material; módulo de corte único partilhado pelas três peças; secções de verificação e casca *manifold* `NoError` (secção 4.3).
- **Melhoria de IoU das falanges (P1–P6)** — a partir do *baseline* medido (tabela da secção 4.4): proximal 0,949 → 0,965 (rácio de volume 1,002); distal std 0,906 → 0,964, short 0,908 → 0,962, thumb 0,879 → 0,972 (rácios 0,992/0,989/0,997), com todas as interfaces funcionais confirmadas byte a byte idênticas (secção 4.4). Os valores finais passam a constituir a referência de regressão.
- **Clevises dos dedos totalmente paramétricos** (v14.56.0) — *ghost-clip* eliminado na Parte 3; costura C0 com o rebordo da casca paramétrica, sem degraus (Figuras 11 e 13); *keyholes* byte-exatos; bocas dos canais verificadas abertas por *flood-fill* voxelizado; trade-off de IoU na banda dos nós documentado na secção 4.5.
- **Concordância parede→coroa da casca** (`KNEE_R`, v14.56.0) — vinco de ~90° substituído por filete cilíndrico com espessura de parede preservada (Figura 12); modelo completo *manifold* `NoError` e montagem sem avisos.

### Figuras

- **Figura 1** — Sobreposição da casca dorsal paramétrica (opaca) com a malha original alinhada (translúcida). `img/fig01-shell-sobreposicao-ghost.png`
- **Figura 2** — Secção transversal da casca com o *ghost*: parede uniforme e furos dos canais de cabo no teto. `img/fig02-shell-seccao-transversal.png`
- **Figura 3** — Secção horizontal a Z = 10 mm: paredes laterais a acompanhar o original. `img/fig03-shell-seccao-horizontal.png`
- **Figura 4** — Vista colorida por peça (`debug_colors`) com casca e parede posterior desativadas, ilustrando os comutadores por peça. `img/fig04-partes-por-cores.png`
- **Figura 5** — Chão palmar paramétrico em vista de topo sobre o *ghost*: abas frontais sob os clevises e apoios do polegar. `img/fig05-chao-topo-ghost.png`
- **Figura 6** — Modelo completo da palma (renderização isométrica, geometria integralmente avaliada). `img/fig06-modelo-completo-iso.png`
- **Figura 7** — Montagem completa em vista inferior: chão paramétrico soldado a paredes, orelhas e clevises, com os dedos montados. `img/fig07-assembly-vista-inferior.png`
- **Figura 8** — Falange do *fingerator*: superfície contínua obtida por `hull()` de primitivas curvas. `img/fig08-fingerator-falange.png`
- **Figura 9** — Falange proximal reconstruída (vista lateral, baseline IoU 0,947–0,949). `img/fig09-proximal-reconstruida.png`
- **Figura 10** — Falange distal reconstruída (vista lateral, baseline IoU 0,906–0,914). `img/fig10-distal-reconstruida.png`
- **Figura 11** — Clevises paramétricos e junção com a casca, com sobreposição da malha original: costura contínua sem recorte pela malha. `img/fig11-clevises-juncao-ghost.png`
- **Figura 12** — Secção transversal da casca com a concordância parede→coroa (`KNEE_R`): eliminação do vinco com espessura de parede preservada. `img/fig12-shell-joelho-boleado.png`
- **Figura 13** — Canto frontal esquerdo (mindinho) após a interpolação entre níveis dos dedos: costura C0 sem o efeito de "escada". `img/fig13-canto-frontal-esquerdo.png`

## 6. Discussão e limitações

**Dependências de malha remanescentes.** Após a parametrização dos clevises (secção 4.5), apenas duas zonas da palma continuam a recorrer a interseções com o STL original: o polegar (Parte 2, três usos — enchimento, junção com a casca e cúpula dorsal) e a parede posterior do punho (Parte 6, um uso — integralmente *ghost-clip*). Até à sua substituição, o ficheiro não é portátil para o renderizador WASM da plataforma. As vias de substituição estão identificadas: uma quarta estação de controlo ("cuff", Y ≈ −45 mm) na técnica da casca para a parede posterior, e o idioma de "capota" (*hull* de discos achatados menos cópia encolhida, observado nas coberturas de nós do paraglider) para a cúpula do polegar, reutilizando o próprio `shell_station()` rodado para o eixo do polegar.

**Fidelidade orgânica vs. parametrização.** A substituição de geometria medida ponto-a-ponto por primitivas suaves implica um desvio deliberado face ao original — aceite como *trade-off* pela editabilidade e portabilidade, de acordo com a decisão de projeto de abdicar por completo da componente orgânica desde que a superfície resultante seja suave. A sobreposição *ghost* mantém o desvio visível e quantificável.

**Convexidade do invólucro.** O `hull()` é intrinsecamente convexo: concavidades de silhueta (o estreitamento frontal da planta da palma, por exemplo) só são reproduzíveis por interseção com planos/sólidos adicionais ou por composição de múltiplos invólucros. As protuberâncias convexas medidas (o bojo lateral médio) são, pelo contrário, capturadas naturalmente pelas estações de controlo.

**IoU como métrica.** Reitera-se o enquadramento metodológico: o IoU é reportado, não otimizado como fim em si. Nas falanges, a margem entre o *baseline* (0,879–0,949) e os valores finais (0,962–0,972) proveio de erro sistemático de forma de secção, corrigido sem tocar nas interfaces — e a correção produziu conhecimento sobre o original (a face de fundo da ranhura cilíndrica e concêntrica com o pino; os pés inferiores quase planares da proximal). Os ~3,5 % residuais correspondem a efeitos de "pele" abaixo de 0,2 mm, com retornos fortemente decrescentes, pelo que não se justifica prosseguir a otimização. Para a casca fina da palma, o teto prático do IoU é estruturalmente mais baixo e a verificação por secções e sobreposição é mais informativa. O caso complementar é a banda dos nós (secção 4.5): aí o IoU desceu deliberadamente (0,909 → 0,730) porque o critério de projeto — a suavidade da junção com a casca — prevaleceu sobre a fidelidade a uma zona da malha bruta com defeitos próprios; a métrica cumpre o seu papel ao tornar o custo do critério explícito e rastreável.

**Trabalho futuro imediato.** Quarta estação da casca para a parede posterior do punho; capota paramétrica do polegar; gravação de série/escala (*labels* com proveniência clínica, idioma `do_labels()` do paraglider); gancho de escala global com *inverse-scaling* das interfaces, em articulação com o dimensionamento antropométrico da plataforma; promoção das cópias de trabalho das falanges (`Proximals_v2.scad`, `Distals_v3.scad`) a ficheiros ativos da montagem após validação de impressão.

## 7. Referências

Fontes internas do repositório (consultadas a 11–12 de julho de 2026):

1. **Método de reconstrução** — `openscad-parametric-reconstructor/RECONSTRUCTION_METHOD.md`; ferramenta de verificação `openscad-parametric-reconstructor/scripts/verify_recon.py`.
2. **Modelo reconstruído** — `models/active/pec_phoenix_hand/Palm_left_V2.scad` (v14.51.0–v14.56.0); montagem `_assembly.scad`; falanges `Proximals.scad`, `Distals_v2.scad` e cópias de trabalho `Proximals_v2.scad`, `Distals_v3.scad`; ferragens STEP `phoenix_snap_pins.scad`, `phoenix_tensioner_block.scad`, `phoenix_tensioner_pins.scad` (v14.50.0).
3. **Cyborg Beast** (comunidade e-NABLE) — `models/active/pec_phoenix_hand/cyborgpalm001.scad`: técnica *hull-of-primitives* da palma (módulos `cyborgbeast07palm`, `cyborgbeast07palminsidespace`, `hardwarecutouts`).
4. **Chão de referência** — `models/active/pec_phoenix_hand/Palm_left_floor.scad` (cópia de `openscad-parametric-reconstructor/templates/`).
5. **Família *flexible flyer*/paraglider** (Marcus Mendenhall, 2020–2022) — `models/active/pec_phoenix_hand/paraglider_palm_unlimbited_v3.scad`, `paraglider_palm_unlimbited_v3_tensor.scad`, `paraglider_palm_left_tensor.scad`; originais com dependências em `archive/tests/flexible-flyer-master/flexible_flyer-master/files/`.
6. **Fingerator** (gerador de dedos da mesma família) — cópia local `models/active/pec_phoenix_hand/fingerator.scad`; fonte de referência `~/dev/anatofab/prostfab/converters/fingerator.scad`.
7. **Registo de alterações** — `CHANGELOG.md`, entradas v14.50.0–v14.56.0 (11–12 de julho de 2026).

---

*Documento gerado no âmbito do desenvolvimento da plataforma de geração assistida de próteses; os caminhos citados referem-se ao repositório do projeto. As afirmações quantitativas (IoU, volumes, contagens de parâmetros) correspondem a medições efetuadas nas sessões de trabalho de 11 e 12 de julho de 2026.*

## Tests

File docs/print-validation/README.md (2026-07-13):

# Validação de Impressão — Modelos 3MF Dimensionados por IA (variações de idade)

Este diretório é a **etapa de validação de impressão** que dá seguimento à
[`ai_anthropometric_validation.md`](../ai_anthropometric_validation.md). Onde esse
documento validou os **números** produzidos pelo pipeline de dimensionamento por IA,
aqui fechamos o ciclo até **ficheiros 3MF prontos a imprimir**, gerados pelo caminho
de produção da plataforma, para os **três modelos ativos** em **quatro grupos etários**.

O objetivo é ter, em mãos, peças físicas que atravessem toda a gama de tamanhos
imprimíveis, para inspeção de encaixe, tolerâncias das juntas e comportamento do piso
de escala do Phoenix.

## Método

Cada configuração passou pelo **pipeline vivo real** da plataforma, não por valores
copiados à mão:

1. **Prompt** — reconstruído exatamente como o frontend (`app.js · getAISuggestions`),
   injetando o schema de parâmetros vivo de cada modelo a partir de
   `models/models-config.json` (a lateralidade e a cor são excluídas da lista da IA; a
   lateralidade é fixada em **esquerda** como escolha de UI).
2. **Dimensionamento por IA** — `POST /api/ai/suggest` autenticado
   (`anthropic · claude-sonnet-4-6`) com `patient_text` + `model_id`, pelo que o
   **grounding por dataset** (§2.4 do documento principal) foi ativado. **As 12 execuções
   devolveram `grounded: true`.**
3. **Render** — os parâmetros sugeridos são aplicados como *overrides* OpenSCAD (`-D`),
   com o *layout* de impressão de cada modelo, e exportados para **3MF** (unidades em mm,
   cores por peça preservadas como materiais) via OpenSCAD 2026 — o mesmo motor que a UI
   corre em WASM. Cada pasta guarda também um `.png` de pré-visualização, o `params.json`
   (sugestões da IA + `grounded`) e o `prompt.txt` (prompt exato + texto do paciente).

> **Nota de reprodutibilidade.** A amostragem do LLM é estocástica (§3.4 do documento
> principal): estes ficheiros são **uma extração representativa** por perfil. Os
> invariantes (ordenação dos dedos, intervalos, proporções) mantêm-se entre execuções;
> os milímetros exatos variam ±2–3 mm.

## Perfis (arquétipo homem brasileiro, variado por idade)

Mesmo arquétipo do "Homem 28 🇧🇷" do documento principal, declinado em quatro idades:

| Pasta | Etiqueta | Texto do paciente |
|---|---|---|
| `child_8` | Rapaz 8 | `boy, 8 years old, 26kg, 128cm height, Brazil, small hands` |
| `teen_15` | Adolescente 15 | `teenage boy, 15 years old, 60kg, 170cm height, Brazil, slim build, arm length 62cm` |
| `adult_28` | Homem 28 | `man, 28 years old, 82kg, 180cm height, Brazil, arm length 70cm` |
| `elderly_70` | Homem 70 | `man, 70 years old, 78kg, 172cm height, Brazil, arm length 68cm` |

## Parâmetros aplicados (execução representativa, mm)

Largura da palma + comprimentos dos dedos que a IA devolveu por perfil. Todos
respeitam a ordenação anatómica (médio mais longo, mindinho mais curto, polegar <
médio) e caem nos intervalos por idade.

### Flexy Beast

| Perfil | palm_breadth | índic | médio | anelar | mindinho | polegar |
|---|--:|--:|--:|--:|--:|--:|
| child_8 | 64 | 57 | 60 | 58 | 46 | 50 |
| teen_15 | 78 | 70 | 74 | 72 | 57 | 62 |
| adult_28 | 90 | 76 | 84 | 80 | 65 | 71 |
| elderly_70 | 84 | 65 | 69 | 66 | 52 | 62 |

### Paraglider · Hand

| Perfil | palm_breadth | índic | médio | anelar | mindinho | polegar |
|---|--:|--:|--:|--:|--:|--:|
| child_8 | 63 | 55 | 60 | 55 | 43 | 48 |
| teen_15 | 78 | 69 | 74 | 68 | 56 | 67 |
| adult_28 | 90 | 76 | 84 | 76 | 65 | 71 |
| elderly_70 | 84 | 66 | 69 | 66 | 52 | 62 |

### UnLimbited Phoenix (só largura da palma)

| Perfil | palm_breadth pedido | HandPerc efetivo | nota |
|---|--:|--:|---|
| child_8 | **82** | 100 % | **limitado ao piso** — a IA estimou ~62 mm mas o Phoenix não imprime abaixo de 82 mm; devolveu 82 sem `HandPerc_override` (correção v14.18.0 a funcionar) |
| teen_15 | 88 | ~107 % | |
| adult_28 | 90 | ~110 % | |
| elderly_70 | 84 | ~102 % | |

**Verificação de escala do Phoenix (bbox da palma exportada):** 82 mm → 82.2 × 92.0 ×
30.6 mm; 90 mm → 90.2 × 100.9 × 33.5 mm; rácio 1.098 = exatamente 90/82. A largura pedida
chega à malha ao milímetro e a escala é uniforme.

## Notas de impressão por modelo

- **Flexy Beast** — `print_layout = true`: **um único ficheiro 3MF** com todas as 12
  peças dispostas planas na base de impressão (palma, gauntlet, e as 12 secções de dedo
  coloridas). Escala para o mais pequeno — a escolha certa para o perfil `child_8`.
- **Paraglider · Hand** — `show_assembled = false`: **um único 3MF** com palma, 5 dedos
  e os pinos de pivô em disposição plana.
- **UnLimbited Phoenix** — impresso **uma peça de cada vez**: cada pasta contém **8
  ficheiros 3MF** (`palm`, `fingers`, `phalanx`, `pins`, `box`, `tpins`, `gauntlet`,
  `jig`). É de malha fixa, **só 82 mm e acima** — inadequado para mãos pequenas; para o
  `child_8` fica no piso de 100 %.

### Peças separadas (`parts/`)

Além da placa combinada, o Flexy e o Paraglider trazem cada peça como **ficheiro 3MF
individual** dentro de uma subpasta `parts/` — igual à seleção por peça do modal de
exportação da plataforma. Cada peça é isolada pelos seus *toggles*, **centrada na base
e assente em Z=0** (o mesmo *drop-to-bed* que o frontend faz), e exportada com a **cor
por peça** embebida como material 3MF. Assim pode imprimir-se peça a peça, por cor/material
ou consoante o tamanho da base:

- **Flexy Beast** — 12 peças: `palm`, `gauntlet`, e `<dedo>_base`/`<dedo>_tip` para
  índice, médio, anelar, mindinho e polegar.
- **Paraglider · Hand** — 7 peças: `palm`, `index`, `middle`, `ring`, `pinky`, `thumb`,
  `pins`.
- **UnLimbited Phoenix** — já é per-peça por natureza (os 8 ficheiros ficam diretamente
  na pasta da idade, sem subpasta `parts/`).

## Manifesto de pastas

```
docs/print-validation/
├── README.md                      (este ficheiro)
├── flexy_beast/<idade>/
│   ├── flexy_beast_<idade>.3mf + .png    (placa combinada)
│   ├── params.json + prompt.txt
│   └── parts/<peça>.3mf                  (12 peças individuais, coloridas, assentes)
├── paraglider_hand/<idade>/
│   ├── paraglider_hand_<idade>.3mf + .png
│   ├── params.json + prompt.txt
│   └── parts/<peça>.3mf                  (7 peças individuais)
└── unlimbed_phoenix_hand/<idade>/
    ├── unlimbed_phoenix_hand_<idade>_<parte>.3mf (×8) + .png
    └── params.json + prompt.txt
```

**116 ficheiros 3MF** no total: 8 placas combinadas (4 Flexy + 4 Paraglider) + 76 peças
individuais (48 Flexy + 28 Paraglider) + 32 Phoenix. PNG de pré-visualização a par de
cada placa combinada e de cada peça Phoenix. Idades: `child_8`, `teen_15`, `adult_28`,
`elderly_70`.

_Data de execução: 2026-07-08 · provider `anthropic · claude-sonnet-4-6` · grounding
ativo · OpenSCAD 2026.04.26._

---

# Série de crescimento — a mesma pessoa dos 8 aos 18 anos (só UnLimbited Phoenix)

Segunda campanha (`growth-series/`): em vez de quatro arquétipos independentes, **um
único indivíduo acompanhado ao longo do crescimento**. Partimos do texto do `teen_15`
acima e declinámo-lo em quatro idades coerentes entre si — altura e peso seguem uma
curva de crescimento ~P50 de rapaz brasileiro de constituição magra, e o comprimento
do braço mantém a proporção do perfil original (62 cm / 170 cm ≈ 0,365 da altura).
Só a idade (e as dimensões que dela decorrem) varia; nacionalidade, sexo e
constituição ficam fixos.

| Pasta | Etiqueta | Texto do paciente |
|---|---|---|
| `age_08` | Rapaz 8 | `boy, 8 years old, 26kg, 128cm height, Brazil, slim build, arm length 47cm` |
| `age_12` | Rapaz 12 | `boy, 12 years old, 40kg, 150cm height, Brazil, slim build, arm length 55cm` |
| `age_15` | Adolescente 15 | `teenage boy, 15 years old, 60kg, 170cm height, Brazil, slim build, arm length 62cm` |
| `age_18` | Jovem 18 | `young man, 18 years old, 68kg, 177cm height, Brazil, slim build, arm length 65cm` |

O `age_15` é **byte a byte o mesmo texto** do `teen_15` da campanha principal — serve
de ponte entre as duas séries (e devolveu a mesma largura de palma: 88 mm).

## Método (o que mudou desde 2026-07-08)

Mesmo pipeline vivo (prompt do frontend → `POST /api/ai/suggest` autenticado →
OpenSCAD com *overrides* `-D` → 3MF), mas o **modelo Phoenix evoluiu** entretanto:

- **Comprimento por dedo** (v14.48–14.51): além de `palm_breadth_mm`, o schema expõe
  agora `index/middle/ring/pinky_finger_length_mm`, `thumb_length_mm` e a divisão
  proximal/distal (`*_base_length_mm`). A IA dimensiona os 11 parâmetros, não só 1.
- **Seletor de peça → toggles**: o antigo enum `part` (8 peças, um ficheiro por peça)
  deu lugar a `print_layout` + 6 `show_*`. A exportação da plataforma passou a ser
  **uma placa única** com todas as peças planas na base — como o Flexy/Paraglider —
  pelo que cada pasta traz a placa combinada **e** uma subpasta `parts/` com as 6
  peças isoladas pelos toggles (`palm`, `fingers`, `thumb`, `pins`, `gauntlet`,
  `tensioner`), centradas na base e assentes em Z=0.

**As 4 execuções devolveram `grounded: true`.**

## Parâmetros aplicados (execução representativa, mm)

| Perfil | palm_breadth | HandPerc efetivo | índice | médio | anelar | mindinho | polegar |
|---|--:|--:|--:|--:|--:|--:|--:|
| age_08 | **82** | 100 % (piso) | 60 | 62 | 59 | 55 | 52 |
| age_12 | **82** | 100 % (piso) | 68 | 71 | 68 | 58 | 62 |
| age_15 | 88 | ~107 % | 74 | 78 | 74 | 62 | 62 |
| age_18 | 90 | ~110 % | 76 | 84 | 80 | 65 | 62 |

A progressão é monótona em todos os dedos e a ordenação anatómica mantém-se em todas
as idades (médio mais longo, mindinho mais curto, polegar < médio).

**O piso de escala e o comprimento por dedo são agora independentes** — a observação
central desta série. Aos 8 e aos 12 anos a palma fica limitada ao piso de 82 mm
(100 %), tal como o `child_8` da campanha principal; mas, com o comprimento por dedo
paramétrico, **os dedos continuam a crescer entre os dois perfis presos ao piso**
(bbox dos dedos: 42.1 mm → 46.1 mm em Y; polegar 37.0 → 43.0 mm), o que reduz na
prática o impacto do piso em mãos pequenas.

**Verificação de escala (bbox da palma exportada):** 82 → 82.2 mm; 88 → 88.2 mm;
90 → 90.2 mm. Rácios 88.18/82.17 = exatamente 88/82 e 90.18/82.17 = 90/82 — a largura
pedida chega à malha ao milímetro e a escala é uniforme. Todas as malhas renderizam
sem erro (CSG `manifold NoError`; palma/pinos/gauntlet são malhas fixas importadas).

## Manifesto

```
docs/print-validation/growth-series/
├── render-report.json                 (bbox de cada placa e peça, por idade)
└── unlimbed_phoenix_hand/<idade>/
    ├── unlimbed_phoenix_hand_<idade>.3mf + .png   (placa combinada, cores por peça)
    ├── params.json + prompt.txt
    └── parts/<peça>.3mf + .png                    (6 peças isoladas, assentes em Z=0)
```

**28 ficheiros 3MF**: 4 placas combinadas + 24 peças individuais, cada uma com o seu
PNG de pré-visualização. Idades: `age_08`, `age_12`, `age_15`, `age_18`.

_Data de execução: 2026-07-12 · provider `anthropic · claude-sonnet-4-6` · grounding
ativo · OpenSCAD 2026.04.26._

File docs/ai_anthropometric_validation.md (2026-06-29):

# Dimensionamento Antropométrico Assistido por IA de uma Mão Protésica Paramétrica — Um Estudo de Validação

## Resumo

Este documento relata uma validação estruturada do **pipeline de sugestão de parâmetros por
IA** da plataforma, no qual um modelo de linguagem de grande dimensão (LLM) infere um conjunto
completo de dimensões antropométricas para uma mão protésica paramétrica imprimível em 3D (o
modelo *Flexy Beast*) a partir de descrições de pacientes em texto livre. A hipótese central é
que um utilizador não especialista — que desconhece as medições clínicas da mão — pode ainda
assim obter um desenho anatomicamente plausível e pronto a imprimir descrevendo o paciente em
linguagem corrente. Definimos um protocolo de validação (conformidade com os intervalos,
proporcionalidade dos dedos, plausibilidade no adulto, escalonamento adequado à idade e
lateralidade contralateral) e aplicamo-lo em dois experimentos que abrangem todo o espectro
realista de entradas: medições diretas ricas, dados parciais e apenas dados demográficos. Em
ambos os experimentos o modelo produziu, em todos os casos, resultados válidos, dentro dos
intervalos e anatomicamente ordenados. Documentamos também o comportamento não determinístico
do sistema, um falso positivo heurístico no nosso próprio teste e uma lacuna genuína de
robustez (lateralidade inferida em vez de instruída). Os resultados são uma única amostra
representativa; o protocolo — e não os milímetros exatos — é o contributo.

---

## 1. Introdução e Motivação

A adaptação protésica convencional exige que um clínico capture um conjunto de medições da mão
(largura da palma, comprimentos por dedo, etc.) usando paquímetros e pontos de referência
normalizados. O utilizador-alvo desta plataforma é, pelo contrário, um **leigo** — um paciente
ou familiar — que não tem nem o vocabulário nem os instrumentos para essa tarefa. O passo de IA
existe especificamente para colmatar esta lacuna: transforma a informação que o utilizador
*consegue* fornecer no conjunto de parâmetros estruturado e com precisão milimétrica que o
modelo CAD paramétrico requer.

Isto reformula o critério de sucesso. Não se pede ao sistema que reproduza uma medição clínica
de referência; pede-se-lhe que produza um **ponto de partida razoável, seguro e editável** a
partir de entradas escassas, que o utilizador (ou um técnico revisor) afina depois através dos
controlos de parâmetros antes da exportação. A acessibilidade para o utilizador com pouco
conhecimento é, portanto, o valor primário de desenho, e é ela que determina o que validamos:
comportamento gracioso em todo o espectro de riqueza das entradas, autoconsistência anatómica e
correção relevante para a segurança (nomeadamente o lado da mão).

---

## 2. Arquitetura do Sistema

### 2.1 Visão geral do pipeline

```
free-text description
   → frontend prompt construction (app.js · getAISuggestions)
       · injects the live Flexy Beast parameter schema (name, caption, type, min/max, current)
       · also sends patient_text + model_id for server-side grounding
   → POST /api/ai/suggest    (server/routes/aiRoutes.js, JWT-authenticated, rate-limited)
       · dataset grounding (§2.4): findBestProfileMatch → buildGroundingBlock
         appends the closest population group's measured means to the prompt
   → aiService.callAnthropic (claude-sonnet-4-6)
   → JSON object { param: value, ... }
   → applySuggestions()      (drops unknown keys; updates only valid params)
   → parametric re-render (OpenSCAD WASM)  →  user fine-tuning  →  STL export
```

### 2.2 Construção do prompt

O prompt é montado por pedido e incorpora as definições de parâmetros do modelo **atual**, de
forma a que o LLM esteja sempre fundamentado no schema vivo (nomes, legendas, intervalos
permitidos, valores atuais) em vez de numa lista fixa. Instrui o modelo a (i) tratar os
parâmetros antropométricos como medições anatómicas em milímetros, (ii) estimar a partir de
normas populacionais quando apenas são dados dados qualitativos, (iii) preservar proporções
inter-dedos realistas, (iv) emitir apenas nomes de parâmetros conhecidos dentro de cada
intervalo e (v) deixar os parâmetros não anatómicos (hardware/visibilidade/cor) nos seus
valores por omissão, salvo se implicados. O template completo é reproduzido no Apêndice A.

### 2.3 Schema antropométrico canónico

Os nomes dos parâmetros estão deliberadamente alinhados com o pipeline de importação
antropométrica da plataforma (ver `CLAUDE.md`), de modo a que a saída da IA, os perfis
populacionais importados de CSV e a introdução manual partilhem todos um único vocabulário de
medição. Os intervalos de referência do adulto usados como limites de plausibilidade são
reproduzidos no Apêndice B.

### 2.4 Grounding por dataset (a partir da v11.0.0)

Originalmente o LLM estimava os casos qualitativos a partir das **suas próprias** normas
populacionais derivadas do treino; os datasets populacionais importados pela plataforma
(Apêndice C) eram uma biblioteca de referência passiva que não entrava no prompt. As sugestões
são agora opcionalmente **grounded** sobre esse dataset:

1. O frontend envia `patient_text` e `model_id` juntamente com o prompt.
2. `server/services/profileMapping.js · findBestProfileMatch` pontua cada perfil populacional
   armazenado em função do texto livre por **género**, **categoria etária + proximidade
   numérica de idade** e **país**, com um critério de desempate a favor de datasets
   representativos de percentil/média e de levantamentos de mãos, e seleciona a melhor
   correspondência (acima de uma pontuação mínima; caso contrário, nenhuma).
3. `mapProfileToModelParameters` projeta as `measurements` desse perfil nos parâmetros do
   modelo vivo — limitadas aos limites de cada parâmetro — e `buildGroundingBlock` anexa as
   médias medidas ao prompt como uma âncora explícita (ver Apêndice A).
4. O prompt instrui que **as medições fornecidas do paciente têm precedência** sobre estas
   médias populacionais, pelo que o grounding enviesa os *priors*, não os dados do utilizador.

O grounding é best-effort e retrocompatível: se nenhum perfil corresponder (ou o dataset estiver
vazio) o pedido prossegue sem grounding, e a resposta indica `grounded: true|false`. O mesmo
módulo `profileMapping` alimenta o seletor "Population baseline" do configurador, pelo que o
caminho de seed-from-dataset e o caminho de grounding por IA partilham uma única tradução.

> **Robustez do matcher (v14.16.0).** O parser de género/idade era originalmente apenas em
> inglês e usava tokens de substring, pelo que o token masculino `'m,'` correspondia às unidades
> `"mm,"`/`"cm,"` — **qualquer** texto de paciente que contivesse uma medição era lido como
> *masculino*, e os termos em português/espanhol eram ignorados. Na prática isto ancorava quase
> todas as descrições (incluindo crianças e mulheres) em *ANSUR I Male 50th Percentile*. Foi
> detetado pelas simulações end-to-end abaixo e corrigido: os tokens correspondem agora em
> fronteiras de palavra Unicode e são multilingues (EN/PT/ES), a análise de idade compreende
> `anos`/`años`, e os valores numéricos de `age_group` (`"7"`, `"18-30"`, `"80+"`) são
> classificados em criança/adulto/idoso com proximidade numérica. Os testes unitários herméticos
> estão em `test/profileMapping.test.js` (`npm run test:unit`).
>
> **Extração opcional por LLM (v14.16.0).** Para descrições em texto livre ou multilingues onde
> o parser determinístico deixa uma lacuna, `aiService.extractPatientAttributes` (uma chamada
> rápida `claude-haiku-4-5`) extrai `{gender, age}` para ancorar a correspondência. Corre
> **apenas** quando a análise determinística está incompleta e degrada-se graciosamente (recorre
> à análise de texto) em qualquer erro ou chave em falta — pelo que as entradas estruturadas não
> incorrem em nenhuma chamada adicional.

Isto desloca a questão de validação relevante para as entradas qualitativas: onde a §4 mediu os
*priors* não auxiliados do modelo, as execuções com grounding testam adicionalmente se o sistema
**se ancora no grupo correspondente** sem sobrepor as medições declaradas. Os invariantes da
§3.3 (schema, ordenação, intervalo, escalonamento) continuam a aplicar-se inalterados.

---

## 3. Metodologia

### 3.1 Modelo e configuração

| Item | Valor |
|---|---|
| Modelo CAD alvo | `flexy_beast` (SCAD paramétrico totalmente autocontido) |
| Fornecedor / modelo de LLM | Anthropic · `claude-sonnet-4-6` |
| Endpoint | `POST /api/ai/suggest` (autenticado como admin) |
| Contrato de saída | objeto JSON único, parâmetro→valor |
| Data da execução | 2026-06-05 |

### 3.2 Desenho experimental

Foram definidos dois experimentos para cobrir eixos complementares:

- **Experimento 1 — inferência a partir de proxies populacionais (§4).** Cinco perfis descritos
  puramente por proxies corporais *indiretos* (idade, sexo, peso, altura, região, comprimento do
  braço) **sem** quaisquer medições da mão. Isto isola a capacidade do modelo de inferir a
  antropometria da mão a partir de dados demográficos — o caso dominante do "utilizador comum" no
  mundo real.
- **Experimento 2 — espectro de entradas e lateralidade contralateral (§5).** Três perfis de
  amputação unilateral abrangendo entradas ricas → escassas, testando o uso literal das medições
  fornecidas, a estimativa proporcional dos campos em falta e o espelhamento correto para o lado
  amputado.

### 3.3 Critérios de validação

Cada sugestão é avaliada segundo cinco critérios:

1. **Conformidade com o schema** — a saída é parseável como JSON; cada chave é um parâmetro real
   do modelo; cada valor numérico situa-se dentro do seu `min`/`max` declarado.
2. **Proporcionalidade dos dedos** — médio ≥ indicador, médio ≥ anelar, o mindinho é o mais
   curto, polegar < médio.
3. **Plausibilidade no adulto** — para perfis adultos, cada medição cai dentro do intervalo
   canónico do adulto (Apêndice B).
4. **Escalonamento adequado à idade** — os menores escalam abaixo das normas do adulto e o
   hardware das articulações flexíveis é reduzido para mãos de criança.
5. **Correção da lateralidade** (Experimento 2) — `mirrored` é definido de modo a que a prótese
   corresponda ao lado *amputado*, isto é, o espelho da mão medida/intacta.

### 3.4 Sobre o não determinismo

A amostragem do LLM é **estocástica**: entradas idênticas não produzem saídas idênticas. Por
conseguinte, as tabelas numéricas abaixo são uma **única extração representativa**, e a §4.4
quantifica a variação entre execuções que observámos. Os critérios de validação foram concebidos
para serem *invariantes distribucionais* — propriedades que se espera que se verifiquem em cada
extração — em vez de afirmações sobre valores específicos. Esta é a postura epistémica adequada
para validar um componente estocástico: testamos a forma e a segurança da saída, não as suas
coordenadas exatas.

---

## 4. Experimento 1 — Inferência a partir de proxies populacionais

### 4.1 Perfis (apenas proxies indiretos)

| # | Etiqueta | Entrada em texto livre |
|---|---|---|
| 1 | Homem 28 🇧🇷 | `man, 28 years old, 82kg, 180cm height, Brazil, arm length 70cm` |
| 2 | Menina 10 🇯🇵 | `girl, 10 years old, 32kg, 138cm height, Japan, small frame` |
| 3 | Mulher 65 🇳🇬 | `woman, 65 years old, 68kg, 160cm height, Nigeria, arm length 62cm` |
| 4 | Homem 50 🇩🇪 | `man, 50 years old, 95kg, 175cm height, Germany, broad hands, arm length 66cm` |
| 5 | Adolescente 15 🇮🇳 | `teenage boy, 15 years old, 60kg, 168cm height, India, slim build, arm length 67cm` |

### 4.2 Resultados (execução representativa, mm)

| Parâmetro | Homem 28 🇧🇷 | Menina 10 🇯🇵 | Mulher 65 🇳🇬 | Homem 50 🇩🇪 | Adolescente 15 🇮🇳 |
|---|---|---|---|---|---|
| `palm_breadth_mm` | 90 | 62 | 74 | 95 | 72 |
| `index_finger_length_mm` | 76 | 52 | 64 | 78 | 64 |
| `middle_finger_length_mm` | 80 | 55 | 68 | 82 | 68 |
| `ring_finger_length_mm` | 76 | 52 | 65 | 79 | 64 |
| `pinky_finger_length_mm` | 62 | 42 | 50 | 63 | 51 |
| `thumb_length_mm` | 70 | 48 | 58 | 72 | 58 |
| `joint_dia` (hardware) | 7 | **5** | *default* | 7 | 7 |
| `joint_thick` (hardware) | 4 | **2** | *default* | 4 | 4 |

*Negrito = a IA reduziu proativamente o hardware das articulações flexíveis para uma mão de
criança. "default" = parâmetro omitido, deixando o valor atual do modelo (segundo a regra
"deixar o hardware salvo se implicado").*

### 4.3 Validação

**Resumo: 14 verificações passadas, 1 aviso, 0 falhas.**

- **Conformidade com o schema:** os 5 foram parseados; cada chave válida; todos os valores
  dentro do intervalo. ✓ *(Esta é também a verificação de regressão para a correção do prompt —
  o prompt anterior estava codificado para o modelo "Fingerator" removido e direcionava o LLM
  para parâmetros inexistentes que eram depois silenciosamente descartados na aplicação.)*
- **Proporcionalidade:** os 5 satisfazem médio-mais-longo / mindinho-mais-curto / polegar <
  médio. ✓
- **Plausibilidade no adulto:** os três adultos caem todos dentro dos intervalos canónicos do
  adulto. ✓
- **Escalonamento por idade:** a Menina 10 escalou para `palm_breadth` 62 mm e reduziu o
  hardware para 5 mm / 2 mm sem instrução. ✓
- **Aviso (não é erro do modelo):** o adolescente de 15 anos recebeu `palm_breadth` 72 mm; a
  heurística genérica do nosso teste "`menor ⇒ < 70 mm`" assinalou-o, mas 72 mm está correto
  para um adolescente alto e magro de meia-adolescência cuja mão tem essencialmente tamanho
  adulto. A falha está na asserção demasiado estrita, não na sugestão.

### 4.4 Variação entre execuções (ilustrando a §3.4)

Comparando esta execução com uma execução independente anterior sobre o mesmo perfil Homem 28
🇧🇷:

| Campo | Execução anterior | Esta execução | Δ |
|---|---|---|---|
| `palm_breadth_mm` | 88 | 90 | +2 |
| `index_finger_length_mm` | 74 | 76 | +2 |
| `middle_finger_length_mm` | 78 | 80 | +2 |
| `thumb_length_mm` | 68 | 70 | +2 |

A variação é pequena (±2–3 mm, ~2–3%) e **preserva todos os invariantes** (ordenação,
intervalos, proporções). O perfil Mulher 65 🇳🇬 ilustra adicionalmente o não determinismo
*estrutural*: numa execução o modelo emitiu explicitamente `joint_dia`/`joint_thick`, noutra
omitiu-os (deixando os valores por omissão) — ambos válidos sob o contrato do prompt. Isto
limita o jitter esperado para os consumidores a jusante e reforça que a saída da IA é um **ponto
de partida**, refinado pelo utilizador, não uma prescrição fixa.

---

## 5. Experimento 2 — Espectro de entradas e lateralidade contralateral

### 5.1 Fundamentação

Na prática, o utilizador fornece *aquilo que tem*. Para uma **amputação unilateral**, os dados
mais ricos disponíveis são a medição direta da **mão contralateral intacta**; a prótese deve
então ser produzida para o lado **oposto** (amputado), isto é, o espelho geométrico da mão
medida. O parâmetro `mirrored` (`false` = esquerda, `true` = direita) governa isto. Este
experimento abrange três níveis de riqueza e verifica tanto o uso literal dos valores fornecidos
como a atribuição correta do lado.

### 5.2 Perfis

| Cenário | Entrada | Lado amputado → prótese necessária |
|---|---|---|
| Contralateral direto | medições completas da mão ESQUERDA intacta | direita → DIREITA |
| Parcial + demográficos | homem 40; apenas `pb=90` da mão DIREITA intacta | esquerda → ESQUERDA |
| Apenas demográficos | mulher 30, asiática oriental, 158 cm | direita → DIREITA |

### 5.3 Resultados (execução representativa, mm)

| Cenário | `palm_breadth` | ind / méd / anel / mind / polegar | `mirrored` da IA | Lado correto |
|---|---|---|---|---|
| Contralateral direto | 84 *(literal)* | 72 / 78 / 75 / 58 / 64 *(literal)* | `true` | ✓ |
| Parcial + demográficos | 90 *(literal)* | 76 / 80 / 76 / 62 / 72 *(estimado)* | `false` | ✓ |
| Apenas demográficos | 72 *(estimado)* | 61 / 65 / 62 / 48 / 57 *(estimado)* | `true` | ✓ |

### 5.4 Conclusões

- **As medições fornecidas são usadas literalmente** — o modelo não reestima sobre os dados que
  o utilizador forneceu (todos os seis valores no cenário 1; o único `pb=90` no cenário 2 passou
  diretamente).
- **A entrada parcial combina-se corretamente** — os valores fornecidos são retidos e os campos
  em falta são estimados *proporcionalmente em torno deles*.
- **Apenas-demográficos degrada-se graciosamente** — o caminho central de baixo conhecimento
  produz um conjunto completo e plausível.
- **A lateralidade esteve correta nos três** — o modelo produziu o espelho do lado intacto.

> ⚠ **Ameaça à validade — a lateralidade é *inferida*, não *instruída*.** O prompt não menciona
> lateralidade nem espelhamento; o modelo deduziu-a a partir do fraseado em linguagem natural
> ("missing the RIGHT hand"). Com `claude-sonnet-4-6` e entrada em frase completa isto foi
> fiável ao longo das execuções, mas para abreviaturas clínicas concisas (por ex. *"L hand
> pb84, R amp"*) não está garantido. Como uma mão do lado errado é inutilizável e um não
> especialista pode não reparar, uma regra explícita de contralateral/espelho no prompt é o
> reforço recomendado (ver §9).

---

## 6. Experimento 3 — Validação Geométrica Inter-Modelos (IA → exportação STL)

Onde os Experimentos 1–2 mediram as estimativas **numéricas** do LLM, o Experimento 3 fecha o
ciclo até à **geometria impressa**, em **todos os três** modelos ativos. Cada execução conduz a
interface `/edit` real de ponta a ponta com Playwright/Chromium — login → escrever uma descrição
de paciente → `POST /api/ai/suggest` real (`claude-sonnet-4-6`, grounding ativo) → aplicar →
**Exportar STL** pelo caminho de produção OpenSCAD-WASM — e depois mede cada malha exportada com
`trimesh`. *(Execuções: 2026-06-28, matcher de grounding corrigido na v14.16.0.)* Quatro
configurações por modelo: um **baseline** por omissão mais três perfis de paciente (criança /
mulher adulta / homem adulto).

Detalhe por modelo, prompts e tabelas por peça:
[Flexy Beast](flexy-beast-ai-sim/flexy-beast_ai-sizing-dimensional-report_2026-06-28.md) ·
[Paraglider](paraglider-ai-sim/paraglider-hand_ai-sizing-dimensional-report_2026-06-28.md) ·
[UnLimbited Phoenix](phoenix-ai-sim/unlimbited-phoenix-hand_ai-sizing-dimensional-report_2026-06-28.md).

### 6.1 Modelos em teste

| Modelo | Entradas antropométricas | Exportação | Mecanismo de escala | Mão mínima imprimível |
|---|---|---|---|---|
| Flexy Beast | largura da palma + 5 comprimentos de dedos | 12 peças de impressão | `xScaleFactor=(breadth+5)/55`, escalas de comprimento por dedo | pequena (capaz para criança) |
| Paraglider · Hand | largura/comprimento/espessura da palma + 5 dedos | 7 peças | `overall_scale=breadth/66.4` (palma) + por dedo | tendencialmente adulto |
| UnLimbited Phoenix | apenas largura da palma | modelo inteiro, 1 ficheiro | `HandPerc=breadth/82×100` uniforme, **limitado a 100–160 %** | **≈82 mm (100 %)** |

### 6.2 Dimensionamento por IA entre modelos (parâmetros aplicados)

Todas as doze execuções devolveram `grounded: true` e valores dentro do intervalo e
anatomicamente ordenados.

| Perfil | Flexy `palm_breadth` / `middle` | Paraglider `palm_breadth` / `middle` | Phoenix `palm_breadth` |
|---|---|---|---|
| baseline | 83 / 72 | 83 / 72 | 82 |
| criança | 62 / 56 | 62 / 56 | **82** *(no piso; +`HandPerc_override=76`)* |
| mulher | 77 / 77 | 77 / 76 | **82** *(no piso)* |
| homem | 96 / 86 | 96 / 86 | 96 |

Os dois modelos multi-parâmetro dimensionam-se de forma **quase idêntica** (independentemente de
qual modelo está carregado — a estimativa segue o paciente, não a malha). O Phoenix expõe o piso
da sua única entrada: perfis abaixo de 82 mm não podem ser expressos, pelo que a IA devolveu 82 —
exceto para a criança, onde recorreu à saída de emergência `HandPerc_override` (ver §6.5, defeito
3).

### 6.3 Palma exportada — rácio de escala vs baseline (maior dimensão)

| Perfil | Flexy Beast | Paraglider | Phoenix |
|---|---:|---:|---:|
| baseline | 1.000 (124.2 mm) | 1.000 (113.7 mm) | 1.000 (92.0 mm) |
| criança | 0.761 | 0.747 | 0.760 † |
| mulher | 0.932 | 0.928 | **1.000** ‡ |
| homem | 1.148 | 1.157 | 1.171 |

† A criança do Phoenix só encolheu porque a IA usou `HandPerc_override = 76` (76 %), o que
**contornou** o piso de 100 % do modelo — um defeito, agora corrigido (§6.5); após a correção é
1.000.
‡ A mulher do Phoenix (estimada em ~77 mm < 82) é **limitada ao piso de 100 %** — o modelo não a
consegue imprimir mais pequena, por desenho. O Flexy e o Paraglider escalam-na para baixo
suavemente (~0.93).

A geometria segue as entradas **linearmente** nos dois modelos escaláveis (comprimento/largura da
palma do Flexy ≈ 1.49–1.52 constante; Paraglider ≈ 1.37 constante), confirmando que o mapeamento
de parâmetros chega à malha.

### 6.4 Fidelidade à geometria de origem

| Modelo | Referência estática | Concordância |
|---|---|---|
| Flexy Beast | STLs de demonstração daprice (160 %) | palma dentro de ~1 % quando dimensionada para a mesma mão |
| Paraglider | malha da palma Flexible Flyer Reborn | corresponde após a correção de escala da palma (§6.5, defeito 2) |
| UnLimbited Phoenix | `UnLimbited_Arm_V2.2.scad` a montante (mesma malha embebida) | **exato** — ≤ 0.06 mm; idêntico byte a byte a 100 % |

### 6.5 Defeitos encontrados e corrigidos

Fechar o ciclo dos números até à **geometria** foi o que fez emergir estes — nenhum era visível
nas verificações numéricas dos Experimentos 1–2. Os três foram corrigidos e re-verificados de
ponta a ponta.

| # | Âmbito | Defeito | Correção |
|---|---|---|---|
| 1 | Grounding (todos os modelos) | `findBestProfileMatch` ancorava **todos** os pacientes em *ANSUR I Male 50th* — o token masculino `'m,'` correspondia às unidades `"mm,"`/`"cm,"`, e a análise era apenas em inglês (§2.4) | **v14.16.0** — tokens multilingues em fronteira de palavra Unicode, classificação por idade, extração opcional por LLM |
| 2 | Palma do Paraglider | A palma Reborn estava **congelada** no tamanho de 83 mm — `scaled_palm()` é importada com `use` (com escopo léxico) e lia o `overall_scale=1.25` codificado da biblioteca, ignorando `palm_breadth_mm` | **v14.17.0** — reaplicar a escala no local de chamada |
| 3 | Override do Phoenix | `HandPerc_override` (intervalo `[0:160]`) tinha uma zona morta `1–99` **sem piso**; a IA usou `76` para imprimir uma palma de criança a 62 mm, abaixo do mínimo suportado de 100 % | **v14.18.0** — limitar também o ramo do override a 100–160 % |

### 6.6 Orientação para seleção de modelo

Os três modelos são **complementares**, não intermutáveis, por tamanho imprimível:

- **Flexy Beast** — escala para o mais pequeno; a escolha certa para **crianças** e mãos
  estreitas.
- **Paraglider · Hand** — entradas antropométricas mais ricas (acrescenta
  comprimento/espessura da palma); bom para adultos num intervalo amplo.
- **UnLimbited Phoenix** — malha fixa, **apenas 82 mm e acima**; excelente fidelidade ao
  original mas inadequado para mãos pequenas (o seu próprio texto de ajuda redireciona para o
  Flexy Beast).

Para os perfis de criança e mulher aqui, o Flexy Beast ou o Paraglider são corretos; o Phoenix
limita-os ao piso. Isto é agora consistente na geometria após a correção do defeito 3.

---
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

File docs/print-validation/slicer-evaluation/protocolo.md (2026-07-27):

# Protocolo — Ensaios de preparação para impressão (HandFab)

**Data de execução:** 2026-07-14
**Âmbito:** gerar dados verificáveis, por linha de comando de dois fatiadores
(Bambu Studio e PrusaSlicer), sobre a **preparação para impressão** dos modelos
paramétricos da HandFab. Os valores aqui produzidos são **estimativas de
software de fatiamento**, não medições físicas.

> **Distinção fundamental.** Um fatiador estima tempo, comprimento de filamento,
> massa e volume a partir das trajectórias que planeia. Não são medições reais de
> uma impressão física, nem indicadores de desempenho estrutural. A verificação
> de malha (estanquidade, faces degeneradas) é uma propriedade **geométrica** do
> ficheiro e **não** um indicador de resistência mecânica da peça impressa.

Os ensaios organizam-se em duas **séries** complementares: **Série A** (projectos
arquivados, fatiados como preparados) e **Série B** (comparação digital
controlada). Os nomes dos ficheiros CSV conservam a designação técnica original.

---

## 1. Programas, versões e ambiente

| Item | Valor |
|---|---|
| Bambu Studio | `BambuStudio-01.10.02.76` (AppImage PR-6008) |
| PrusaSlicer | `2.8.1+linux-x64-GTK3-202409181416` |
| Python / NumPy | 3.12.3 / 2.4.4 (só na análise geométrica) |

Os *checksums* SHA-256 dos AppImage e os comandos exactos estão em
[`comandos_e_versoes.txt`](comandos_e_versoes.txt).

**Isolamento.** O AppImageLauncher do sistema interceptava os AppImage e
provocava *segfault* em modo headless; por isso os AppImage foram **extraídos** e
executou-se o binário interno (`AppRun`), como o protocolo previa. O `HOME` foi
redirigido para um directório de trabalho dedicado e o PrusaSlicer usou um
`--datadir` próprio, de modo a **não alterar os perfis globais do utilizador**.

---

## 2. Série A — projectos arquivados (fatiados como preparados)

Quatro *project files* preservados em `docs/print-validation/`:

| # | Projecto | Ficheiro | Fatiador / impressora | Material |
|---|---|---|---|---|
| 1 | Flexy Beast, 15 anos | `flexy_beast_teen_15_print.3mf` | Bambu Studio / Bambu Lab A1 | PLA |
| 2 | UnLimbited Phoenix, 15 anos | `unlimbed_phoenix_hand_teen_15_print_project.3mf` | Bambu Studio / A1 | PLA |
| 3 | UnLimbited Phoenix, 15 anos | `unlimbed_phoenix_hand_teen_15_print_project_PETG.3mf` | Bambu Studio / A1 | PETG |
| 4 | Paraglider Hand, 15 anos | `paraglider_15_teen_prusa_print_profile.3mf` | PrusaSlicer / Prusa MINI | PLA |

**Duplicado localizado:** existe uma cópia distinta (checksum diferente) do
projecto Phoenix PLA em
`unlimbed_phoenix_hand/teen_15/unlimbed_phoenix_hand_teen_15_print_project.3mf`.
A Série A usou a versão de topo (`docs/print-validation/…`).

**Descoberta metodológica.** Os quatro ficheiros contêm geometria, definições de
processo/filamento e o *layout* de placa — mas **não** os resultados de
fatiamento: no Bambu, o `slice_info.config` só tinha o cabeçalho; no PrusaSlicer,
não havia G-code embebido. Por isso cada projecto foi **re-fatiado com o seu
próprio perfil embebido** (tal como preparado) para obter tempo, filamento e
massa. O layout e a orientação foram mantidos.

**Parâmetros efectivos** (extraídos das configurações embebidas — ver
[`raw/extract_params.txt`](raw/extract_params.txt)):

- Bambu (3 casos): A1, bico 0,4 mm, perfil base "0.20mm Standard @BBL A1" mas com
  **altura de camada real = 0,24 mm** (o campo `layer_height` foi alterado; o nome
  do perfil não reflecte o valor efectivo), 2 paredes, 4 topo / 3 base, 15% grelha,
  **suportes em árvore orgânica** (só na base, regiões críticas, limiar 35°),
  `auto_brim` 5 mm. Caso 3 usa PETG (slot de filamento `GFG00`).
- PrusaSlicer (Paraglider): Prusa MINI (MINIIS), bico 0,4 mm, perfil
  "0.20mm SPEED @MINIIS 0.4", **camada 0,20 mm**, 2 perímetros, 5 topo / 4 base,
  15% grelha, **sem suportes**, sem aba.

Resultados em [`resultados_projectos_arquivados.csv`](resultados_projectos_arquivados.csv).

---

## 3. Série B — comparação digital controlada (12 casos)

Três modelos (**Flexy Beast**, **Paraglider Hand**, **UnLimbited Phoenix**) × quatro
perfis (**child_8, teen_15, adult_28, elderly_70**), fatiados sob **uma única
condição virtual comum**:

| Variável (controlo) | Valor fixo |
|---|---|
| Impressora | Bambu Lab A1, bico 0,4 mm |
| Filamento | Bambu PLA Basic @BBL A1 |
| Altura de camada | 0,20 mm |
| Paredes/perímetros | 2 |
| Enchimento | 15%, padrão grelha |
| **Suportes (política única)** | **desligados** (`enable_support = 0`) |
| Aba | `auto_brim` |
| Orientação/layout | orientação das peças mantida (`--orient 0`); o fatiador apenas coloca (`--arrange 1 --ensure-on-bed`); a 2.ª placa A1 é criada automaticamente quando não cabe numa |

> Esta série de ensaios **não** é uma impressão física nem uma recomendação de
> imprimibilidade. É uma **comparação digital controlada** da exigência de
> preparação dos três modelos à mesma escala de definições.

**Input de cada caso = conjunto de peças imprimíveis já exportadas pela
plataforma** (não o modelo montado; ver §4): Flexy 12 peças, Paraglider 7 peças,
Phoenix 8 peças.

**Nota de resolução de herança (Bambu CLI).** Ao carregar o preset de filamento de
sistema via `--load-filaments`, o CLI **não** resolvia a cadeia de herança:
`filament_density` e `filament_max_volumetric_speed` ficavam a 0, produzindo
**massa = 0 g** e tempos irreais (≈11 h). Corrigiu-se **aplanando a herança** do
preset (densidade 1,26; caudal 21 mm³/s) — ficheiro
[`raw/configs/pla_basic_a1_resolved.json`](raw/configs/pla_basic_a1_resolved.json).
Todos os 12 casos foram fatiados com o filamento resolvido.

Resultados em [`resultados_campanha_controlada.csv`](resultados_campanha_controlada.csv).

---
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

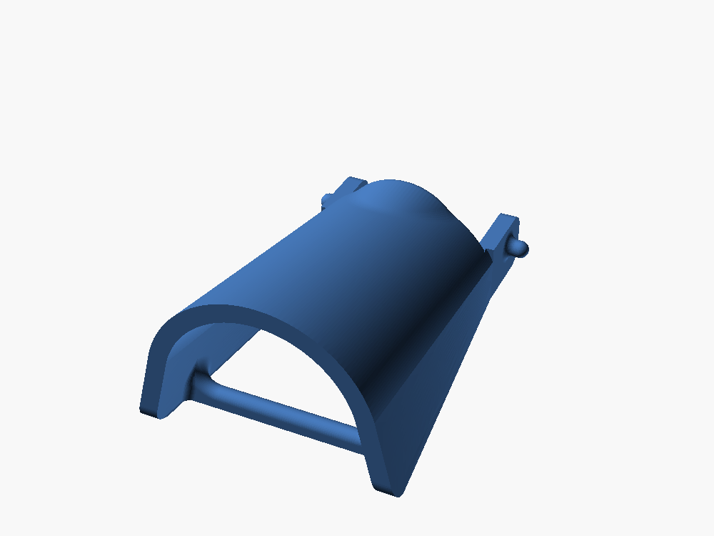
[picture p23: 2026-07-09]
docs/print-validation/unlimbed_phoenix_hand/child_8/unlimbed_phoenix_hand_child_8_jig.png

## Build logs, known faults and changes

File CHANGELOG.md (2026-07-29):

# Changelog

All notable changes are recorded here.

Version format: `MAJOR.MINOR.PATCH`
- Bump **MAJOR** on breaking changes
- Bump **MINOR** on new features
- Bump **PATCH** on bug fixes

Entry format follows [Conventional Commits](https://www.conventionalcommits.org/):
`type: description` — types: `feat`, `fix`, `security`, `refactor`, `docs`, `chore`

## v14.79.0 — 2026-07-29

fix: **deploy — the FTPS mode no longer stages its own scratch.** `deploy.sh ftp` writes its hash manifest and changed-file list beside the staging dir (`deploy.manifest` / `deploy.changed` in the repo root), so every run after the first collected the previous run's scratch and shipped it to production. Both are now in `EXCLUDES`, next to the rest of the deploy machinery.

## v14.78.0 — 2026-07-29

feat: **UnLimbited Phoenix — the gauntlet is previewed thermoformed (as a tube), not flat.** The arm guard prints as a flat plate and is then heat-formed over the Jig, so the assembled view now shows the formed part while the print-bed layout / STL export keeps the flat `Gauntlet_V4()` unchanged. New generator `scripts/phoenix_bend_gauntlet.py` bakes the wrap once into `phoenix_gauntlet_curved.scad` (`Gauntlet_V4_curved()`, registered as a model dependency): the plate is cut by `x = const` planes — edge-deterministic, so the mesh stays watertight for the manifold backend — and each vertex is remapped by arc length onto a half-elliptical forearm section (flat base, arched top), its own thickness becoming an outward normal offset. The section is set by the hinge, not the jig: the square tab holes sit 30 mm of plate from the crown, so the ears come out **vertical — parallel to the palm's own hinge ears** — exactly when that arc equals the section's quarter perimeter, which solves the arch height from its half-width (28 × 6.95 mm at the ear, rounding out to 66 × 26 mm at the elbow). The hinge bosses are stiff, so they do not roll with the shell either: everything past the bend line (`FLAT_ARC = 22`, clear of the whole boss, which spans arc 22.15..38.14) hangs straight down as one **flat, vertical plane**, so the disc stays exactly round and the face the washer meets is planar and square to the hinge axis. The fold runs on a real radius (`R_FOLD = 2`), since folding on a zero radius makes the plate's own thickness overlap itself on the inside of the crease — the slivers that showed up along the ear neck. Along the guard the bend line *migrates* outward until it reaches the base of the arch, where a vertical drop is what the section does anyway, so the fold fades with no pleating (z cutting planes over the whole length, since the fold's position varies along it; blending the two positions instead crumples the shell, pulling the free edge millimetres out of place). Finally, the ears have to end up **outboard** of the palm's wrist wall (palm boss | ear | washer | pin head) and no amount of bending gets them there: nothing 30 mm along the plate can sit more than 30 mm from the guard's axis, the palm's wall is already 30.92 mm out, and turning the ear 90° spends several mm more. So the whole guard is **stretched sideways** by one uniform factor (~1.49), solved to land the ear's inner faces exactly on the palm's wall at world x 24.08/85.92 — one global scale rather than a local flare, which is what keeps the discs round and the neck free of folds. Their holes sit on the palm's wrist-pin axis at z 8.50; the wrist mouth comes out 61.8 mm wide, matching the palm shell it clamps, opening to ~68 mm at the elbow. Baked rather than transformed live because the coarse plate needs subdividing before any bend, which would cost seconds per render in the browser WASM build. `GAUNT_CURVED = false` in `phoenix_assembly.scad` restores the flat preview.

fix: **UnLimbited Phoenix — tensioner and washers follow the formed guard.** The formed gauntlet's crown sits over the palm shell's instead of on the print plane, so the guard, the tensioner block and the tensioner pins all lift by the same `GAUNT_LIFT` (18.33 mm — the hinge boss hangs a fixed drop below the crown, so that height is what sets it on the palm's wrist-pin axis) — the block would otherwise be swallowed inside the tube instead of riding its dovetail rail — and the guard butts against the wrist seam (y −236.5) with 0.5 mm clearance. The wrist washers are the hinge's spacers, so formed they move outboard onto the ears' outer faces (x 18.41/91.59) instead of sitting against the palm; flat, they stay where they were. Known approximation: the ears are parallel to the palm's, clamped on its wall and with their holes on its pin axis, but still ~13 mm apart along the forearm — closing that would drive the guard's wrist end into the palm shell.

## v14.77.0 — 2026-07-27

feat: **`./deploy.sh ftp` — SSH-less incremental deploy over FTPS.** New mode: collect → hash the staged tree → upload only content-changed files via a single `curl --config` FTPS session (credentials in git-ignored `.ftp-deploy.conf`, bootstrap from the new `ftp-deploy.conf.example`; per-host manifest in `.deploy-state/`). Never deletes on the server and never touches the live `data/` DB; `--dry-run` previews the changed-file list, `--all` ignores the manifest. Collect excludes extended: `.slicer-work/`, `dist-*.zip`, `docs/print-validation/`, FTP conf + state.

fix: **UnLimbited Phoenix — wrist and thumb pins fully seated.** Wrist pins nudged onto the gauntlet boss holes (`PIN_OFF_WRIST` ±2 mm in X) with flips corrected to `[0,1]` (heads outward on both sides); thumb PIP pin flipped and dropped 0.5 mm onto its hole axis (`PIN_FLIP_THUMB` `[1,1]`, `PIN_OFF_THUMB` PIP `z −0.5`). New per-pin rotation hooks `PIN_ROT_MCP/PIP/THUMB/WRIST` (applied after the offset, about the pin's own seat point) for future fine alignment — all zeroed, so every other pin renders identically.

docs: **add slicer-evaluation suite** (`docs/print-validation/slicer-evaluation/`) — verifiable Bambu Studio + PrusaSlicer CLI slicing evidence for dissertation Annex D: protocol, exact commands/versions/SHA-256 checksums, Série A (4 archived projects as-prepared) and Série B (12 cases, 3 models × 4 profiles under a common virtual condition) result CSVs, geometry/manifold checks, and raw slicer outputs. Also commits the previously documented print projects (Cyborg Beast teen_15 `.3mf`, Phoenix teen_15 PETG `.3mf`, `palm-body-dimensions.md`).

chore: gitignore FTP deploy credentials/state (`.ftp-deploy.conf`, `.deploy-state/`), slicer scratch (`.slicer-work/`), release archives (`dist-*.zip`), and thesis-test SQLite journal files (`data/*.db-shm/-wal`).

## v14.76.0 — 2026-07-23

fix: **UnLimbited Phoenix — thumb pins seated on the part holes, rectangular head into the palm recess.** `PIN_OFF_THUMB` zeroed (was a `[1,1,1]` fudge, leaving both thumb pins ~1 mm off the MCP/PIP hole axes — pins now sit exactly on the holes by construction, same as the fingers) and `PIN_FLIP_THUMB` set to `[1,0]`: the MCP pin is flipped so its rectangular snap-pin head faces the thumb saddle's rectangular recess (thumb-local −X side; recess side identified on the palm mesh, flip semantics verified by isolated `pin(0)`/`pin(1)` renders — flip=1 ⇒ head at −X).

## v14.75.0 — 2026-07-22

feat: **UnLimbited Phoenix — washers get their own visibility toggle** (`show_washers`). The two wrist-pin cup washers are no longer bundled under `show_tensioner`: new `show_washers` boolean in `UnLimbitedPhoenix.scad` / `phoenix_assembly.scad` / `_assembly.scad` and a new Visibility checkbox in `models-config.json` (EN/PT captions + help; `show_tensioner` texts updated to block-and-pins only). The washers also now appear in the print-bed layout (two flat washers beside the tensioner parts) so the toggle exports them like any other part.

fix: **UnLimbited Phoenix — washers seated on the gauntlet wrist holes.** The washers previously floated at the palm wrist pins with their bores along X (both cup faces pointing the same way). The gauntlet previews flat (it thermoforms around the arm), so its wrist holes run through Z: each washer now lies flat on its gauntlet boss, bore concentric with the measured hole centres (31.86,−151)/(92.14,−151) at boss top z=5.8, flat base against the plate and cup up to receive the pin head. `WASHER_ROT`/`WASHER_POS` are now per-washer arrays. Verified by orthographic renders (bores see-through concentric on both sides).

docs: **add palm/hand-body dimension table across the growth series** (`docs/print-validation/palm-body-dimensions.md`). Axis-aligned bounding box (X/Y/Z, mm) of the **hand body = isolated palm** for the three active models (Flexy Beast, Paraglider Hand, UnLimbited Phoenix) at four AI-sized ages (child_8 / teen_15 / adult_28 / elderly_70). The palm already includes the **thumb-mount saddle** (the structure rigidly joined to the palm where the thumb articulates); the thumb digit, the four fingers, and the gauntlet are excluded because they print as separate parts — and because the assembled thumb sits in opposition (pointing −Z), including it would nearly double the measured Z (e.g. Flexy child_8: 37.1 mm palm-only vs 74.5 mm with the posed thumb). Rendered from the stored `params.json` suggestions via OpenSCAD 2026.04.26 in assembled pose (`print_layout=false`) with the palm isolated by toggles; bbox measured with `test/thesis/helpers/stlMetrics.js` (`analyzeSTL`). Three tables: **nominal (digital)** plus **as-printed** dimensions corrected for **natural thermal shrinkage** with **per-part variation** — each part draws its own `s` from a narrow material band (PLA 0.27–0.33 %, PETG 0.37–0.43 %) via a deterministic FNV-1a hash of its identity (model + age + material), so the tables reflect real part-to-part dispersion yet regenerate byte-identically. At the mid-band 0.3 % the PLA figures reproduce the original hand-measured reference table to <0.001 mm, confirming those were as-printed PLA values. Fully reproducible.

## v14.73.0 — 2026-07-14

docs: **add Cyborg Beast teen_15 print project** (`docs/print-validation/cyborg_beast_teen_15_print_project.3mf`). Same live pipeline and same patient text as the Phoenix teen_15 project (`teenage boy, 15 years old, 60kg, 170cm height, Brazil, slim build, arm length 62cm`), now driven through the Cyborg Beast schema: AI sizing via the reconstructed frontend prompt + `POST /api/ai/suggest` grounding (`grounded: true`, `claude-sonnet-4-6`) returned `palm_breadth_mm: 79` with anatomically-ordered fingers (middle 75 longest, pinky 58 shortest, thumb 67) and the proximal/distal split. The 13 printable parts (palm, 4×base+tip fingers, thumb base+tip, gauntlet, thermoform liner) were rendered flat via OpenSCAD `print_layout=true` (`mirrored=false`, left hand) and arranged by Bambu Studio under the **exact Phoenix PLA profile** (Bambu Lab A1 0.4, `0.24mm Draft`, 2 walls, 15% grid, tree(auto) supports @35°, auto_brim 5mm, PLA Basic). Sliced clean across 3 A1 plates: 175.0 g PLA total, ~13h print time.

## v14.72.0 — 2026-07-14

refactor: **coherent parameter interface across all four models.** Every model's parameters now follow the same canonical group order — `Component → Anthropometric → Segment split → Hardware → Gauntlet → Options → Visibility → Colors → Arm` (groups a model lacks are simply skipped) — so switching models in the UI presents a consistent layout instead of a per-model ordering. Cyborg Beast's singleton `Palm liner` group was merged into `Options`. Config-only reorder — parameter names, values and behaviour are unchanged.
refactor: **normalize the laterality parameter — Phoenix `LeftRight` (enum "Left"/"Right") → `mirrored` (boolean)**, matching Flexy Beast, Cyborg Beast and Paraglider. `UnLimbitedPhoenix.scad` now branches on `!mirrored`; the config entry mirrors the shared `mirrored` enum (Left=false/Right=true, `role:"laterality"`). Laterality stays UI-only and role-based, so the AI/profile logic is untouched. No saved-config migration needed: laterality is never restored from saved configs (it is skipped in `applySuggestions`), so the rename cannot silently flip a saved hand. Verified with left/right renders (thumb + finger order correctly mirror).
refactor: **normalize the view toggle — Paraglider `show_assembled` (true=assembled) → `print_layout` (true=flat)**, matching Cyborg Beast and Phoenix. `paraglider_hand.scad` branches on `print_layout`; the model's `exportLayout` is now `{print_layout:true}`. The toggle is preview-only and export-overridden, so old saved configs are unaffected in any geometric way. Verified: assembled preview and flat print-bed layout both render.
test: sync the thesis Phoenix frozen config (`test/thesis/fixtures/frozen-configs.json`) to the renamed `mirrored` param.
chore: tidy the `_applyExportLayout` comment in `app.js` (dropped the obsolete `show_assembled` example; comment-only, no behaviour change).
docs: bring `docs/relatorio-adaptacao-antropometrica.md` fully current and expand it into the complete per-model technical analysis — inherited state, files, scaling formulas and anthropometric wiring for each of the four models (Flexy Beast, Cyborg Beast, Paraglider Reborn, UnLimbited Phoenix), the `profileMapping.js` bridge, the cross-cutting AI/grounding fixes, the Flexy↔Cyborg gauntlet unification (v14.70), and the interface-coherence/parameter-normalization work (v14.72).

## v14.71.0 — 2026-07-14

test: sync the REP-DET frozen Flexy Beast fixture (`test/thesis/fixtures/frozen-configs.json`, config `REP-DET-001`) with the v14.70.0 gauntlet unification. Dropped the now-removed `gauntlet_width_mm`/`gauntlet_length_mm` params and added the Cyborg-shared cuff defaults (`wrist_circumference_mm: 160`, `gauntlet_tilt: 0`, `gauntlet_length_scale: 0.7`, `gauntlet_rim_hole_d: 2.5`). REP-DET compares each render to the first successful run of the same campaign (self-consistency, `ref = ok[0].metrics`) with no stored golden hash, so no baseline regeneration is required.

## v14.70.0 — 2026-07-14

feat: **Flexy Beast now uses the same forearm gauntlet as the Cyborg Beast.** The two hands share the Cyborg Beast palm and wrist hinge (identical wrist-pin axis Y=-27/Z=5.5 and wrist-fin |X|=26.6), so one cuff fits both. The bespoke primitive half-pipe gauntlet that was inlined in `flexy_beast.scad` (~120 lines of `g_*` modules) is removed and replaced by an `include <gauntlet.scad>` — a copy of the Cyborg Beast's organic-shell reconstruction (`Normal Gauntlet with Tensioner`, embedded polyhedron + parametric hole recut). The seating math is ported verbatim from the Cyborg Beast (prongs nest inside the palm wrist fins, auto-seated on the wrist-pin axis for any girth/length/tilt), wrapped in the hand's uniform `scale([xScaleFactor…])` so the local-frame seat lands on the scaled palm bore.
feat: **Flexy Beast gauntlet is now sized anthropometrically.** The old `gauntlet_width_mm`/`gauntlet_length_mm`/`gauntlet_wall_mm`/`gauntlet_pos_adjust`/`strap_splay_adjust` parameters are replaced by the Cyborg Beast set: `wrist_circumference_mm` (canonical anthropometric field — cuff girth = circumference/π + clearance, so imported profiles and AI grounding now auto-size the cuff via `profileMapping.js`), `gauntlet_tilt`, `gauntlet_length_scale`, `gauntlet_rim_hole_d`. `show_gauntlet`, `wrist_pin_dia`, `wrist_pin_clearance` and `color_gauntlet` are unchanged. `gauntlet.scad` registered as a model dependency so the in-browser WASM loader mounts it; `aiGuidance` updated. Verified with local OpenSCAD renders: assembled view, print layout (cuff exports as its own part), wrist-joint seating (prong pin-hole round and coaxial with the palm hinge), and a child-scale render (palm 62 mm / wrist 130 mm) — all manifold, no errors.

## v14.69.0 — 2026-07-13

feat: **thesis evaluation test suite (`test/thesis/`)** — reproducible, protocol-driven infrastructure that produces dissertation evidence for three families: repetibilidade/reprodutibilidade (`REP-*`), robustez (`ROB-*`) and acessibilidade WCAG 2.2 AA (`ACC-*`). New commands `npm run test:thesis[:repetition|:robustness|:a11y:local|:a11y:public|:ai:live]`. Each campaign writes a fresh, non-overwriting evidence dir under `test-results/thesis-evaluation/AAAA-MM-DD_HH-MM-SS_<campaign>/` with `metadados.json`, structured JSON/CSV results, STL/screenshot/trace artefacts, the Playwright HTML report and a SHA-256 `manifesto_evidencias.csv`. REP-DET renders+exports each frozen config ≥10× through the real OpenSCAD-WASM pipeline and classifies geometric equivalence with a pre-declared tolerance (dependency-free binary/ASCII STL mesh analyser: faces, vertices, bbox, volume, watertight/manifold, degenerate faces); REP-XBR compares chromium/firefox/webkit; REP-AI is split into a MOCKED schema/limits/laterality/recovery suite (never a real AI repetition) and an OPT-IN live dispersion suite gated by `RUN_LIVE_AI_TESTS=1`. ROB-* cover limits/invalid/contradiction/uncovered-population/model-floor/service-failure/render-failure/export-without-geometry, each classified passa/falha controlada/falha não controlada/inconclusivo. ACC-* run `@axe-core/playwright` across auth/dashboard/profile/config/AI/3D states plus an explicit manual-verification checklist; the public campaign is strictly non-destructive and unauthenticated. Local campaigns use an isolated synthetic DB on port 3100; no secrets are written to any artefact.
feat: **`HANDFAB_DB_PATH` env seam in `server/db.js`** — optional override of the SQLite path so automated campaigns run against an isolated synthetic database without touching production data. Backward compatible: unset → `data/app.db` as before; no runtime behaviour changes.
feat: **`LOGIN_RATE_LIMIT_MAX` env override in `server/routes/authRoutes.js`** — optional cap on the login rate limiter so automated campaigns that log in repeatedly from one IP are not throttled. Backward compatible: unset in production → the original 5-per-15-minutes limit is unchanged.
chore: add `@axe-core/playwright` devDependency (4.12.1); ignore `test-results/` (large evaluation artefacts, preserved locally and copied selectively to the dissertation annex).

## v14.67.0 — 2026-07-13

chore: **track anthropometric datasets & generator scripts under `data/`.** The blanket `data/` ignore was excluding source data along with the SQLite DB. Narrowed the rule to DB-only (`app.db`, `app.db-*`, `app.db.bak-*`, `*.db`, `.~lock.*`) so `ansur_1988_complete.csv`, `ansur_1988_hand_arm.csv`, `multi_population_hand.csv`, and the `generate_ansur_csv.py` / `generate_multi_population_hand_csv.py` generators are now version-controlled. Live DB, backups, WAL/SHM sidecars, and LibreOffice lock files stay ignored.

## v14.68.0 — 2026-07-13

refactor: **pec Phoenix palm — thumb dorsal crown de-creased (the "pregas" are gone).** The crumpled triangular pleats and the curling cornice "sail" lip on the thumb dorsal were the `thumb_dome()` skin's own triangulation: every quad split on a fixed diagonal turned the south/cornice saddle rows into convex ridges. Two PART-2-only edits: (1) `THUMB_DOME_Z` interior nodes Laplacian-smoothed (3 passes, clamped |Δ|≤1.6 mm; silhouette rows/cols and the crisp east-bevel kept exact — no fillet), (2) `thumb_dome()` now splits each roof quad along its lower pair (valley-preferring), so the shared edge is a soft groove instead of a convex crease. Pure re-triangulation + node smoothing: dorsal crown reads as one continuous fall, cornice lip gone. Envelope preserved (dorsal deviation vs ghost mean 0.86→0.90 mm, p95/max marginally better); facets 2524→2510 (thumb) / 104484→104462 (full). Cornice/deck/fin/welds untouched; still ghost-free; full model trimesh-watertight, NoError.

## v14.66.0 — 2026-07-13

refactor: **pec Phoenix palm — thumb dome + shell-junction mesh simplified (−36% facets).** PART 2 face-count reduction with the form preserved: `thumb_junction()` sphere `$fn` 32→12 (chord error ~0.02 mm; the visible weld is the ruled hull, not the sphere tessellation) and the redundant `THUMB_JR` y=−2 station dropped (byte-identical to the y=−7 row) → junction 2644→632 facets (−76%); `thumb_dome()` T stations 21→18 (dropped t=7/10/18, each reconstructible to ≤0.30 mm; all 9 S rows kept — the two-way saddle needs them). Thumb-only STL 3934→2524 facets (−35.8%). Surface deviation vs the previous thumb: mean 0.003 mm, max 0.27 mm — silhouette unchanged. Keyhole/channels/prongs/fin line and the shell+floor weld untouched; still ghost-free; full model trimesh-watertight, NoError.

## v14.65.0 — 2026-07-13

fix: **pec Phoenix palm — cable channels no longer sealed by the dorsal fins; fins re-measured; ring/index ramps de-bulged.** PART 4 `finger_fins()`/`finger_fin_caps()` now `difference()` out the shared `cable_channels()` so a fin can never re-close a channel mouth (ghost-style under-blade routing); the pinky mouth (−29.4,26.5,14.8), which was plugged by the pinky spine bridge (not the fin), gets a new `kn_ch1_trench()` notch (same idiom as the existing ch3/ch4 trenches). Flood-fill: all four finger channel mouths now OPEN to air. Fin table re-measured from the ghost (pinky yf 24.4→25.0, base 13→14.5, depth 5.5→4.3; ring/middle/index depth 5.68→4.35 etc.). PART 3: `kn_ramp()` gained an optional mid control row so the ring/index shell→knuckle ramps fall in two chained crisp hulls instead of one straight facet that overshot the ghost's convex fall (ring y25 +4.12→+3.76, index y26 +2.14→+1.61 mm). Honest limit: the rim-adjacent overshoot on the ring/index side is inherited from the PART 1 shell riding ~2–5 mm above the ghost there — nulling it fully needs a shell-station change (out of scope). Full model trimesh-watertight, OpenSCAD NoError; `_assembly_v2.scad` clean, proximal clip fins still engage.

## v14.64.0 — 2026-07-13

feat: **pec Phoenix palm — thumb mount fully parametric; the model is now 100% ghost-free.** PART 2 rebuilt with the Cyborg Beast / paraglider idioms: `thumb_dome()` (skin over measured `THUMB_DOME_T/S/Z` sections along the 50° prong frame), `thumb_body`/`thumb_web`/`thumb_deck`/`thumb_cornice`, parametric `thumb_slot()` clevis pocket, `thumb_fin()` (measured `THUMB_FIN_PTS` on the unchanged blade line), `thumb_trench()` cable saddle, and `thumb_junction()` — the same crown→cowl sphere-hull ramp used at the finger/wrist rims, probed from the current `shell_solid()` (`THUMB_JR_XA/XB`) for a fluid shell weld. The three ghost-clipped pieces (`thumb_fill`/`thumb_shell_junction`/`thumb_top_round`) are gone: `import(ghost_stl)` now appears ONLY in the show_ghost display overlay — the whole palm is parametric. Solid prong overlaps replaced the old tangential graze, so the full model is now trimesh **watertight** (the 2 residual non-manifold edges are fixed) and OpenSCAD NoError. Keyhole bore/slot, cable channels and the fin's functional line unchanged. Known follow-up: the dome arrays are coarse (faceted) and want a density/refinement pass.

## v14.63.0 — 2026-07-12

docs: **validação de impressão — série de crescimento (UnLimbited Phoenix).** Nova campanha em `docs/print-validation/growth-series/`: a mesma pessoa (rapaz brasileiro magro, arquétipo do `teen_15`) aos 8, 12, 15 e 18 anos — altura/peso numa curva ~P50, braço a 0,365 da altura; só a idade varia. Pipeline vivo (prompt do frontend → `/api/ai/suggest` grounded → OpenSCAD `-D` → 3MF), agora sobre o schema Phoenix pós-v14.48: a IA dimensiona os 11 parâmetros (palma + 5 dedos + divisões proximais). 4/4 `grounded: true`; progressão monótona; palma no piso de 82 mm aos 8 e 12 anos **mas com dedos a crescer entre os dois** (42.1→46.1 mm) — piso de escala e comprimento por dedo comprovadamente independentes. Escala verificada na malha (bbox da palma = 82.2/88.2/90.2 mm, rácios exatos 88/82 e 90/82). 28 3MF (+28 PNG): placa combinada `print_layout` + 6 peças isoladas por toggles (`parts/`), assentes em Z=0; README do print-validation atualizado com a secção da série.

## v14.62.0 — 2026-07-12

feat: **pec Phoenix palm — direct inclined transitions front AND back; wrist back wall now parametric (ghost only in the thumb).** Front: new `KN_RAMPS`/`kn_ramp()` — one ruled inclined face per finger band, starting ON the crown skin (`KN_RAMP_Y0`=20.5) and rising over the Y=23 rim clip face to land tangent on the prong crests; the junction slabs became invisible interior fill; rounding defaults dialed down (`KN_EDGE_R` 1.8→0.6, `KN_BULGE`→0) with all tops re-probed on the current shell. Back: PART 6 `wrist_back()` rewritten from a ghost clip into a fully parametric wrist cuff — measured band slabs (`WBAND`, reusing PART 5's `WALL_PROFILE`) + five inclined spans (`WR_RAMPS`/`wr_ramp()`, crown→ears/visor, lip held at z24 to keep the wrist-mouth clearance) with byte-identical ear bore/counterbore re-cuts, shared `cable_channels()` and new strictly-interior `wr_channel_entries()`. The exposed vertical rim faces and recessed channels at both rims are gone. **`import(ghost_stl)` in geometry now exists only in PART 2 (thumb).** Channels improved again (ch1 enclosure 0→100% min); keyholes/windows/fins untouched; ear pin/washer seats verified in `_assembly_v2.scad` with the gauntlet swinging clear.

## v14.61.0 — 2026-07-12

feat: **pec Phoenix palm — floor tucked under the wrist-ear curves too.** Same flush-seat treatment as the knuckles/thumb (v14.59.0), now at the wrist: new `floor_wrist_cutter()` removes everything a wrist tab grows beyond the ear centre plane except a protect cylinder coaxial with the hinge-ear disc (r = EAR_R − `floor_seat_inset`), so the tab tip's underside continues the ear's circular silhouette down to the plate — no teal past the curve, no 90° step; the covered run under the side wall keeps the full-height weld. `floor_tab_back_y` −41.9 → −43.0 (nominal reach; the coaxial cut owns the exposed tip). Numeric probe: ≤ −0.082 mm inside the curve at both ears; manifold NoError; `_assembly_v2.scad` clean, arm-guard hinge/washers unaffected.

## v14.60.0 — 2026-07-12

fix: **pec Phoenix palm — thumb mount shape distortion.** Three artifacts diagnosed and fixed in PART 2: the ghost-clipped `thumb_fill()` box bulged through prong B's flat outer face (triangular wedge patches) and its x=38 edge crossed the prong nose (diagonal seam + ledge) — a new `thumb_face_clip()` half-space guard at the prong's outer face plane (`THUMB_YAW`/`THUMB_FACE_U`) extends the flat face cleanly up to the dome; and the old 5×2.5 fin blade + cap primitives (misaligned/short vs the ghost's own fin, so the crown emerged as a chopped fragment and an orphan sliver) were replaced by one generous rounded envelope `thumb_fin()` on the unchanged blade line — the global ghost intersection now keeps the ORIGINAL fin surface as a continuous ridge. Keyhole, channels, prong dims and the fin's functional line untouched (git-diff verified); full model manifold NoError; `_assembly_v2.scad` clean, thumb proximal's clip fin still continues the palm fin.

## v14.59.0 — 2026-07-12

fix: **pec Phoenix assemblies — palm per-part colours actually visible.** In current OpenSCAD an outer `color()` overrides inner ones (verified with a minimal test), so `_assembly.scad`/`_assembly_v2.scad` no longer wrap `model()` in `color(PALM_COL)` — the palm colours itself via the `[Colors]` group.

feat: **pec Phoenix palm — floor tucked under the knuckle/thumb curves (no more 90° steps).** PART 7 front tabs and thumb pads no longer protrude past the curved faces: `FLOOR_FRONT_TABS` is now DERIVED from PART 3's `KN_PRONGS` (auto-tracks the prongs), and new coaxial cutters (`floor_lobe_seat`/`floor_front_cutter`/`floor_thumb_cutter`, the thumb one in the prongs' 50°-yaw frame) carve each tab end into a concave seat that continues the eye-lobe / prong-rounding curve down to the plate. New `[Floor]` params `floor_face_tuck`=0.35, `floor_seat_inset`=0.05; `floor_tab_past` 3.3→4.5 (nominal strip reach; the cut owns the exposed face); the old ghost-derived `FLOOR_FL_PATCH`/`FLOOR_FR_WEDGE` were also tucked under the rebuilt junction slabs. Numeric probe: floor stays 0.07–0.09 mm inside every lobe curve; full model manifold NoError; `_assembly_v2.scad` clean.

## v14.58.0 — 2026-07-12

feat: **pec Phoenix palm — knuckle-band surface smoothing (no more faceted "staircase").** PART 3 refinement round: (1) `kn_rpost()` round-ended cylinder control posts (new `KN_EDGE_R`=1.8) replace the 0.6 mm cube posts, turning every junction hull crease into an arc; (2) `kn_slab()` auto-inserts a bulged mid station (`KN_BULGE`=0.9) on descents >4.5 mm so long flanks are barrels, not flat ruled facets; (3) the rim seam is now near-tangent — `KN_RIM_Y`=22.0 puts the post centres 1 mm behind the rim and every rim-post top was re-probed from the CURRENT `KNEE_R`-filleted shell (the stale pre-fillet profile was the dark recessed band under the crown). Channels improved again (ch1 min-enclosure 67→100%, ch4 avg 83→97%, mouths flood-fill open); keyholes untouched; full model + `_assembly_v2.scad` render NoError.

## v14.57.0 — 2026-07-12

feat: **pec Phoenix palm — per-part colours by default + Customizer reorder.** The `[Features]` show/hide checkboxes moved to the top of `Palm_left_V2.scad`, followed by a new `[Colors]` group with one editable colour per part (shell SkyBlue, knuckles Orange, fins LimeGreen, thumb Tomato, wrist Plum, wrist back MediumPurple, floor Teal — no longer yellow/khaki like its neighbours). `model()` now applies the part colours itself, the solid-yellow default and the separate `model_colored()` are gone, and `debug_colors` now means "explode the thumb into sub-part colours". (Note: in current OpenSCAD an OUTER `color()` overrides inner ones, so the assemblies' `color(PALM_COL)` wrap had to be dropped — see v14.59.0.)

## v14.56.0 — 2026-07-12

feat: **pec Phoenix palm — knuckles (PART 3) fully parametric; shell knee fillet.** The four finger clevises no longer use the ghost STL: `clip_ghost()` deleted; eye lobes are per-physical-prong measured hulls (exact r5.9 foot discs kept, measured hood tops replace the overfill+clip), the backboxes became measured neck/curtain slabs, and the clipped junction band became gap/flank slabs + rounded window pockets whose rim posts follow the parametric shell rim (C0 seam, staircase at the pinky corner removed). Keyholes byte-exact and cut last; shared `cable_channels()` still re-cut (channel enclosure improved: ch1 96%, ch2 100%, mouths flood-fill-verified open). Ghost imports in geometry now: thumb 3 + wrist_back 1 only. Honest note: knuckle-band voxel IoU vs ghost 0.909 → 0.730 — the extra volume is the deliberate smooth shell-continuous junction chosen over raw ghost fidelity (user steer). Also new `KNEE_R` (default 3.5) in `[Shell]`: a per-station fillet cylinder pair tangent to the wall planes rounds the ~90° wall→crown crease, with a concentric cavity copy keeping the wall uniform. Full model manifold NoError; `_assembly_v2.scad` renders clean.

## v14.55.0 — 2026-07-11

feat: **pec Phoenix — `_assembly_v2.scad`, the assembled hand on the IoU-reworked phalanges.** Copy of `_assembly.scad` that `use`s `Proximals_v2.scad` + `Distals_v3.scad` (same seats, tunables and STEP hardware); `_assembly.scad` stays on the original phalanges for comparison. Verified: full and close-up renders clean (0 errors/warnings), fingers/thumb seat correctly with fins and snap pins in the clevises.

## v14.54.0 — 2026-07-11

feat: **pec Phoenix — paraglider-style self-supporting cable channels in the palm.** `Palm_left_V2.scad` channels are now cut by ONE shared `cable_channels()` module (dorsal_shell / front_assembly / wrist_back all use it, so the re-cuts line up) sweeping a "D" cross-section — semicircular floor + chamfered near-flat ceiling, the flexible-flyer channel technique flipped for our floor-down print orientation — with `round_corners` bend smoothing and waypoints retuned to the parametric crown; printed pipe sheaths (`CH_SHEATH_WALL`) carry each channel where it dives out of the roof band. New `[Shell]` params `CH_STYLE` (D / legacy round), `CH_BEND_R`, `CH_SHEATH_WALL`. Verified: sections show all 5 bores embedded with the D ceiling up; shell STL manifold NoError.

feat: **pec Phoenix fingers — fingerator-idiom IoU rework (on copies; originals preserved).** `Proximals_v2.scad`: IoU 0.949 → 0.965 (voxel 0.4 mm; volume ratio 1.002) via 3-station plan taper, asymmetric tilted-ellipse underside scoops, measured 2-circle belly loft and near-planar scoop foot planes; regressions tried and reverted are documented; protected modules (pin_hole, rails, knuckles, fins+caps, pockets) byte-identical (md5-checked). `Distals_v3.scad`: IoU std 0.906 → 0.964, short 0.908 → 0.962, thumb 0.879 → 0.972 (volume ratios 0.992/0.989/0.997) via least-squares-fitted superellipse "egg" sections (fixed 96-vertex skin correspondence), measured pin-concentric slot-end cylinder (r 7.39) + bore-entry counterbores, 5–6 measured tip stations, sloped tendon-groove floor + cord-exit ramp; slot/pin/feat_*/fin invariants byte-identical.

docs: **thesis report — parametric reconstruction of the pec Phoenix hand.** New `docs/pec-phoenix-hand/relatorio-reconstrucao-parametrica.md` (academic European Portuguese, 7 sections, 10 verification figures under `docs/pec-phoenix-hand/img/`): methodology (measure-never-guess, ghost, voxel IoU, manifold), single-file 7-part architecture, the adopted parametric techniques with provenance (Cyborg Beast hull-of-primitives shell, anchored-primitives floor, paraglider D channels + interface inverse-scaling, fingerator phalanx idioms), results and limitations.

## v14.53.0 — 2026-07-11

feat: **pec Phoenix palm — dorsal shell + palm floor rebuilt fully parametric (Cyborg Beast hull technique).** PART 1 `dorsal_shell()` dropped the measured `AY`/`AP` point-cloud loft (~1000 coordinates + BOSL2 `skin()`) for the `cyborgpalm001.scad` hull-of-primitives idiom: one `hull()` over three named control stations (flattened crown ellipsoid + two wall posts each), an independently shrunk cavity hull, then the functional cable-channel cuts. New `[Shell]` Customizer group (`SHELL_WALL`, `SHELL_KNEE_Z`, `CROWN_FLAT/RZ/RY` + per-station `Y/XL/XR/APEX`), defaults = measured envelope. PART 7 `palm_floor_grid()` dropped the measured 45-point outline and its `import(ghost_stl)` front-band clip for a union of named footprint primitives anchored to the parts it mates with (shell feet, clevis aprons + front tabs, ear tabs, thumb pads) smoothed by an offset fillet/round chain; new `[Floor]` Customizer group, basket-weave vents unchanged. Both verified against the ghost overlay and in `_assembly.scad`; full model renders manifold (NoError).

## v14.52.0 — 2026-07-11

feat: **hand side (left/right) is now the first option on every model.** Moved the `role:"laterality"` parameter (`mirrored` / `LeftRight`) to the top of the parameter list in `models/models-config.json` for Cyborg Beast, Flexy Beast, UnLimbited Phoenix and Paraglider Hand Reborn — choosing which hand you are building comes before any measurement. On the Paraglider the selector joins the `Component` group so it sits above the hand/arm component chooser without reordering the groups; everywhere else it leads the `Anthropometric` group. Config-only reorder — parameter names, values and the AI laterality handling (role-based) are untouched.

## v14.51.0 — 2026-07-11

refactor: **pec Phoenix palm — single-file `Palm_left_V2.scad` with per-part checkboxes.** Fused the five part includes (`Palm_left_V2_shell.scad`, `Palm_left_V2_thumb.scad`, `Palm_left_V2_rings.scad`, `Palm_left_V2_fins.scad`, `Palm_left_V2_wrist_back.scad`) inline into `Palm_left_V2.scad` as marked PART sections and deleted the part files. Every integrated part now has its own Customizer checkbox in `[Features]` (`show_shell`, `show_knuckles`, `show_fins`, `show_thumb`, `show_wrist`, `show_wrist_back` — new, previously bundled with `show_wrist` — and `show_grid`), all on by default (shell + fins previously defaulted off). The rings' hardcoded ghost path now reuses the shared `ghost_stl`; `_assembly.scad` verified unchanged.

## v14.50.0 — 2026-07-11

feat: **pec Phoenix hand — adopt the STEP-measured tensioner + snap-pin parts.** Replaced the hand-fitted reconstructions (`Tensioner_Block.scad`, `Tensioner_Pins.scad`, `Snap_Pins_without_Labels.scad`) in `models/active/pec_phoenix_hand/` with the step2scad B-rep reconstructions shared with the UnLimbited Phoenix model (`phoenix_tensioner_block.scad`, `phoenix_tensioner_pins.scad`, `phoenix_snap_pins.scad` — every dimension measured from the STEP faces).
refactor: pec `_assembly.scad` now seats the REAL Phoenix pins via the `*_centered()` helpers — small snap pins (body_1) at the finger/thumb joints, the larger clip pin (body_0) + countersunk cup washer (body_9) at the wrist ears — replacing the cylinder/washer stand-ins. The pins are fixed-size measured parts, so the `PIN_LEN_*`/`PIN_DIA_*` knobs were removed in favour of per-pin head-side `PIN_FLIP_*` switches. Regenerated `_assembly_preview.png`.

## v14.49.0 — 2026-07-11

chore: **repo cleanup — consolidated non-platform material under `archive/`.** Moved the Cyborg Beast reference PDFs and the unused `cyborgbeast07l.scad` into `archive/cyborg-beast/`, and relocated the whole Playwright suite (`tests/` → `archive/tests/`) with its output (`test-results/` → `archive/test-results/`) — kept runnable by pointing `playwright.config.js` `testDir`/`outputDir` at the new paths and fixing `compare_renders.spec.js`'s `test-renders` path (`playwright test --list` finds all 24 tests). Added `archive/` to the `deploy.sh` rsync excludes so none of it ships to production, and dropped the 19 MB reference-STL `stls/` folder (gitignored via `models/**/stls/`). The large untracked reference dumps (`Proximals.stl`, `UnLimbited_Arm_V2.2.scad`, `flexible-flyer-master/`, `flexy-beast-original/`) moved along but stay untracked. Dev-only reorganisation — no app/runtime code changed. Also restored this `# Changelog` header to the top of the file (recent entries had been prepended above it). Bump `index.html` JS cache-buster to 14.49.0.

## v14.48.0 — 2026-07-11

feat: **UnLimbited Phoenix — per-finger parametric length (all five digits).** Each finger and the thumb can now be sized to the patient without distorting the pin holes. The Phoenix meshes are fixed, so a finger is lengthened by splitting its column at the hole-free shaft, keeping the hinge (hole) zones unscaled, stretching only the shaft, and shifting the far end out — the pin holes stay perfectly round and printable. New params `index/middle/ring/pinky/thumb_finger_length_mm` (total MCP→tip, Anthropometric) + `_base_length_mm` (proximal MCP→PIP, Segment split), matching the canonical CLAUDE.md fields so imported profiles populate them. Native reference 72/31, so defaults render identically to the stock finger; the PIP pin and fingertip follow the lengthened proximal, and the flat print layout exports each digit at its custom length (export matches preview). Verified: length change is 1:1 (middle 72→100 → tip reach +27.6 mm), base split redistributes proximal/distal with total held constant, holes stay round, and the whole hand renders manifold with no regression at defaults. Bump `index.html` JS cache-buster to 14.48.0.

## v14.47.0 — 2026-07-10

refactor: **pec Phoenix palm — shared ear-station table for wrist_back.** The hinge-ear positions `[[20.5,-1],[-36.0,+1]]` were duplicated between `wrist()` (Palm_left_V2.scad) and the bore re-cuts in `wrist_back()` (Palm_left_V2_wrist_back.scad) — moving an ear would silently desync the re-cut tunnels. Lifted to a shared `EARS` constant next to the other `EAR_*` params; both call sites now iterate it. Also corrected the re-cut comment: the r3 tunnel does not widen the wall's r2.5 hinge window because the union with the parametric wall (solid in the r2.5–r3 annulus) restores it. Verified zero geometry change (ghost-band boolean-diff volumes bit-identical before/after: missing 81.011 mm³, extra 273.316 mm³).

## v14.46.0 — 2026-07-10

feat: **UnLimbited Phoenix — per-part colours (Colors tab).** Exposed the assembled hand's colours as model parameters, matching Cyborg Beast / Flexy Beast: `color_palm`, `color_index`/`middle`/`ring`/`pinky`, `color_thumb`, `color_pins`, `color_gauntlet`, `color_washers`, `color_tensioner_block`, `color_tensioner_pins`. `phoenix_assembly.scad`'s previously-hardcoded colours now read from these injectable params (via forward-referenced assignments in the includer), so every part is recolourable from the UI. Verified: colour injection re-colours the matching faces headlessly (red palm → 11858 faces) and the Playwright E2E passes. Bump `index.html` JS cache-buster to 14.46.0.

## v14.45.0 — 2026-07-10

feat: **UnLimbited Phoenix — per-part controls replace the single-part selector.** Dropped the `part` dropdown; every part now has its own always-visible toggle (`show_palm`, `show_fingers`, `show_thumb`, `show_pins`, `show_gauntlet`, `show_tensioner`) plus a `print_layout` switch (assembled seated preview ↔ flat print-bed layout for STL export), matching the Cyborg Beast / Flexy Beast pattern (`exportLayout: {print_layout:true}`, Visibility group). The assembled view and the print layout are both gated by the toggles, scaled uniformly by HandPerc and mirrored for a right hand. Full EN/PT captions + help. Verified end-to-end via Playwright (`tests/phoenix_assembly.spec.js`): the part selector is gone, all six toggles + print_layout render as checkboxes, hiding parts re-renders correctly, the print layout lays parts flat, and it stays parametric (right hand, 100–146%).
fix: **Phoenix preview meshes keep the original palm/fingertip detail.** Replaced the v14.42.0 voxel remesh (manifold but soft/blobby) with a MeshFix repair of the stock non-manifold meshes — it resolves only the self-intersecting spots, preserving the original geometry (palm and fingertips deviate ~0 mm at the 95th percentile) while staying watertight-manifold so the browser's manifold backend renders them in the assembled view. Also smaller (`phoenix_preview_meshes.scad` 623 KB vs 1.9 MB). Bump `index.html` JS cache-buster to 14.45.0.

## v14.44.0 — 2026-07-10

fix: **Cyborg Beast thumb segments now match the original reference STLs.** Measuring the original `Thumb_Phal.stl` (31.2 mm) / `Thumb_Finger_w_Bumps.stl` (36.5 mm) against our SCAD parts showed the reconstructed thumb base was ~6 mm too short (24.8 mm — modelled as a shrunk `fingermid(-12)`). Raised the thumb's native reach reference `THUMB_BASE_REACH` 44.93 → 51.3 mm and set the default `thumb_base_length_mm` 22 → 27, so the native base now measures 31.1 mm and the tip 36.5 mm — both within 0.1 mm of the originals — while the world thumb length stays `thumb_length_mm` (thumb_scale compensates) and the PIP hinge stays coaxial. Verified by isolated-module bbox measurement and an assembled render. (Reference STLs added under `models/active/cyborg-beast/stls/`. The palm-dorsal-thickness discrepancy, ~7 mm, is left for a later pass.) Bump `index.html` JS cache-buster to 14.44.0.

## v14.43.0 — 2026-07-10

feat: **Cyborg Beast palm gains the Flexy Beast thermoformable liner.** Ported the `thermoform_mesh` module and added `show_thermoform` + `color_thermoform`: a perforated mesh (offset grid of elongated holes) clipped to the palm interior (`cyborgbeast07palminsidespace()`, already present in `cyborgpalm001.scad`) lines the inside of the palm so a fitter can heat-form it to the patient's own palm. Rendered in both the assembled view and the print layout (fused with the palm), plus a **Palm liner** printable part and EN/PT captions/help.
fix: **Gauntlet now seats on the real palm wrist-pin axis and its wings meet the palm wings.** The auto-seat was solving to a wrong wrist-pin reference (local y=1.4, z=3.3); corrected to the actual palm wrist hinge (y=-27, z=5.5 — the `hardwarecutouts` bore and wrist-fin pin holes), so the gauntlet moves down/back and its prong pin-holes land on the palm pin (verified by threading a test pin through both).
feat: **Gauntlet widened and decoupled X/Z so its wings always align to the palm.** The cuff is now scaled anisotropically: width (X, prong span) is locked to the palm so the prongs nest just inside the wrist fins at x=±26.6 regardless of the wrist measurement, while depth (Z, girth) still tracks `wrist_circumference_mm`. This makes the two gauntlet wings meet the palm's two wings — previously the prongs shrank to ±16 mm (well inside the ±26.6 fins) at typical wrist sizes. Updated the `wrist_circumference_mm` caption/help accordingly.
feat: New gauntlet defaults `gauntlet_tilt = 0` (forearm in line with the hand instead of drooping 12°) and `gauntlet_length_scale = 0.7` (shorter forearm), in both the `.scad` and the model config. Verified: assembled + print-layout renders and a watertight manifold export. Bump `index.html` JS cache-buster to 14.43.0.

## v14.42.0 — 2026-07-10

fix: **Phoenix assembled preview — restore surface definition on the palm and fingertips.** The v14.41.0 manifold fix voxel-remeshed those two meshes at a coarse pitch (palm 1.25 mm), which made them render but stripped all surface detail (a blobby/melted look). Regenerated at a fine pitch (palm 0.4 mm, fingers 0.32 mm) then reduced with manifold-preserving decimation (`manifold3d.simplify`, 0.11–0.14 mm tolerance) — ~38k/26k triangles, detail recovered while staying watertight-manifold. Also converted them from binary-STL imports to embedded `polyhedron()` modules (`phoenix_preview_meshes.scad`), matching how the rest of the model stores geometry: one 1.9 MB `.scad` dependency replaces the two ~3 MB STL deps (they are fixed meshes, no longer parametric). Verified: manifold render keeps all 9 part colours incl. the palm (39k faces); Playwright E2E passes. Bump `index.html` JS cache-buster to 14.42.0.

## v14.41.0 — 2026-07-10

fix: **Phoenix assembled preview now shows the palm and fingertips.** The v14.36.0 assembled view rendered correctly headless but lost the palm and the four distal (fingertip) segments in the browser. Cause: the in-browser preview uses the **manifold** backend, which silently drops any mesh that fails `PolySet→Manifold` conversion, and the stock `Phoenix_Thermo_Palm_2` (palm) and `Phoenix_Fingers_Left` (distals) are **non-manifold** (self-intersections — edges shared by >2 faces: 32 and 12 respectively). They survive when printed one part at a time (no boolean op), but the assembly's implicit top-level **union** forces conversion → both were dropped, leaving only the manifold proximals (`Phoenix_Phalanx_Left`). Fix: ship watertight **voxel-remeshed** manifold copies (`phoenix_palm_manifold.stl`, `phoenix_fingers_manifold.stl`) that the assembled preview `import()`s; the individual **printable part** options still use the exact original meshes. Registered both as model `dependencies` so the WASM loader mounts them. Verified: manifold render now carries all 9 part colours including the palm (0 → 43k faces); Playwright E2E (`tests/phoenix_assembly.spec.js`) confirms the seated hand renders in-browser with no dependency errors and stays parametric (right hand, 100–146%). Bump `index.html` JS cache-buster to 14.41.0.
fix: **Cyborg Beast gauntlet seats on the actual wrist hinge.** Corrected the palm wrist-pin axis the cuff tracks to the real hardware (`G_PIN_Y = -27`, `G_PIN_Z = 5.5` — the wrist-hinge bore / wrist-fin pin holes) and set neutral defaults (`gauntlet_tilt = 0`, `gauntlet_length_scale = 0.7`) so the forearm guard sits flush at the wrist instead of floating off-axis and drooping.

## v14.40.0 — 2026-07-10

feat: **Cyborg Beast gains a parametric forearm gauntlet** (Normal Gauntlet with Tensioner reconstruction, new `active/cyborg-beast/gauntlet.scad`). The cuff auto-seats on the palm's wrist-pin axis — its prongs nest inside the palm wrist fins and track the pin for any girth/length/tilt — and is sized to the wearer by `wrist_circumference_mm` (cuff width = circumference/π + clearance), independently of hand scale. Exposed parameters: `show_gauntlet`, `wrist_circumference_mm`, `gauntlet_tilt` (forearm droop about the wrist pin), `gauntlet_length_scale`, `wrist_pin_dia` + `wrist_pin_clearance`, `gauntlet_rim_hole_d`, and a 12th per-part colour `color_gauntlet`. Registered as a model dependency so the in-browser WASM loader mounts it. Verified end-to-end: browser render + combined 3MF export bake the gauntlet colour as its own material (`tests/cyborg_export.spec.js` updated to the 12-colour set).
chore: deploy + gitignore now exclude `models/**/output/` and `models/**/previews/` (openscad-skill render scratch) so preview PNGs/STLs never ship to production or land in git.
chore: bump `index.html` JS cache-buster to 14.40.0.

## v14.39.0 — 2026-07-10

fix: remove the "Toggle grid" button from the viewer toolbar — the CSS grid backdrop it toggled was not visible behind the rendered model, so the button had no useful effect.

## v14.38.0 — 2026-07-10

fix: wire up the viewer toolbar buttons on the edit screen — zoom in/out, pan, fullscreen and toggle grid were rendered but had no handlers. Zoom drives the `<model-viewer>` camera-orbit radius; Pan is a toggle mode where left-drag moves the camera target instead of orbiting (capture-phase pointer handlers suppress the built-in orbit); Fullscreen expands the whole viewer card (toolbar included, so the button can also exit); Toggle grid overlays a CSS grid behind the model. E2E coverage in `tests/viewer_controls.spec.js`.

## v14.37.0 — 2026-07-10

feat: **Cyborg Beast fingers and thumb now split into independently-sized proximal (base) and distal (tip) segments.** Each printed finger is two pieces — `fingermid` (proximal phalanx, MCP→PIP) and `fingertip` (distal, PIP→tip) — that were previously locked to a single shared `len` lever, so the proximal/distal proportion was fixed. New per-digit parameters `index/middle/ring/pinky/thumb_base_length_mm` set the proximal segment length directly (MCP→PIP; thumb MCP→IP); the distal segment fills the remainder so the total finger length stays fixed. The proximal span is analytic (`fingermid` hinge-to-hinge = `23 + 2·lp/3`, local units) and the distal lever is solved from the existing measured reach curve (`R = 60.85 + slope·len`), so the two levers reduce exactly to the original shared-`len` finger when the split is left at its native default — defaults render identically to before.
feat: `place_finger()`/`fingerlayout()` refactored to two levers `(lp, ld)`: the knuckle seat tracks the proximal lever only (`9.5 + lp/3`) and the tip is pushed out by `lp/3 + ld/3` so the PIP pin stays coaxial through both segments for any split. Verified by render that the MCP hole stays seated on the palm knuckle line and the PIP hole stays a single clean bore, at the default and at extreme proximal-long / tip-short splits.
feat: **Thumb** gets the same control despite its uniform-scale sizing: `thumb_base_length_mm` sets the proximal fraction, the distal lever holds the sub-assembly reach constant so `thumb_scale()` (and therefore the total thumb length) is unchanged by the split, and the PIP join offset is render-calibrated (`-(23.667 + lp/3 + ld/3)`, reproducing the native `-18` at the `-12/-5` split). Thumb reach model `reach_local = 55.84 + 0.6185·lp + 0.77·ld` fitted on a 5×4 lp/ld render grid (max residual 0.74 mm). Proximal and total both land within a hair of exact (e.g. 22 mm / 38 mm proximal on a 65 mm thumb → 65.0 mm total preserved).
feat: **Anthropometric wiring** — the new `*_base_length_mm` params are mapped in `profileMapping.js` to `digits.<finger>.proximal_length_mm` (already present in the importer schema but previously not plumbed to any model), so an imported patient profile / AI grounding baseline now populates the proximal phalanx split, not just total finger length. Updated the model's `aiGuidance` so the AI knows to set `base_length` only when the proximal phalanx is known (≈0.45 × total finger) and always below the total. Full EN/PT captions + help for all five parameters (`Segment split` group). Bump `index.html` JS cache-buster to 14.37.0.

## v14.36.0 — 2026-07-10

feat: **UnLimbited Phoenix Hand now opens on a fully assembled preview** instead of a single bare part. Added an `Assembly (seated hand)` option to the model's `part` selector and made it the default — it renders the palm, four fingers, thumb, finger/wrist pins, gauntlet, tensioner block/pins and washers all seated together, driven by the same `palm_breadth_mm`/`HandPerc` sizing (the whole assembly is wrapped in one uniform `scale()`, so it stays seated at any size and mirrors correctly for a right hand). The existing per-part options (Palm, Fingers, Phalanx, Pins, Box, TPins, Gauntlet, Jig) are unchanged and remain the way to export each printable piece.
refactor: extracted the seated-hand recipe into a shared `phoenix_assembly.scad` module (single source of truth) that is `include`d by both the served `UnLimbitedPhoenix.scad` (for the `Assembly` part) and the `_assembly.scad` dev harness — no recipe duplication. Registered `phoenix_assembly.scad` + the reconstructed `phoenix_snap_pins.scad` / `phoenix_tensioner_block.scad` / `phoenix_tensioner_pins.scad` as model `dependencies` so the in-browser WASM loader mounts them. Verified: headless render (left/right, 100–146% scale), flat-FS include/use resolution matching the WASM virtual filesystem, and a watertight manifold STL export. Bump `index.html` JS cache-buster to 14.36.0.

## v14.35.0 — 2026-07-10

fix: **Cyborg Beast fingers now seat on the palm knuckle hinge line.** Each finger's proximal (first) `fingermid` hinge hole was floating 4.6–7.1 mm past the palm's knuckle hinge holes, so the assembly pin couldn't pass through both. The cause: the original per-finger y-offsets were hand-tuned for the design's small native `len` values, but the anthropometric layer drives `len` over a much wider range, and the fingermid's hole spacing (`11.5 + len/3`) moves with `len`. Fingers are now seated by a new `place_finger()` module with `yoff = 9.5 + len/3`, which lands the proximal hole on the knuckle hinge line (y = 27) for every finger regardless of length. Verified numerically (pin threads through the base and clears the hole) and visually.
fix: `.scad` model source and text dependencies are now fetched with `{ cache: 'no-cache' }` (like models-config.json in v14.33.0), so edits to a model's geometry reach returning browsers instead of a stale cached copy. Bump `index.html` JS cache-buster to 14.35.0.

## v14.34.0 — 2026-07-09

feat: **Integrate the Flexy Beast finger hinges into the parametric model.** The `Finger_Hinge_Plate.scad` connector plate is now generated inside `flexy_beast.scad` as a parametric flexy joint rather than a fixed STL-measured plate. A new `flexy_joint()` module builds the "dogbone" living-hinge connector (two lobes with pin bores joined by a thin flexing web) entirely from the joint hardware and hand scale — `lobe_r = joint_dia/2 + wall`, `web = joint_thick`, length `= knuckleW × scale`, span `= 8 × scale` — so every connector resizes and repositions when the fingers or `joint_dia`/`joint_thick` change.
feat: In the assembled preview each finger carries its two flexy joints (MCP + PIP) in its own frame via `fingerlayout(hinge=true)`, and the thumb carries its two in the thumb frame — so all ten connectors sit in the joint gaps between the segments and follow the finger pose and length automatically. Each connector is oriented (`rotate([90,90,0])`) so its pin bore runs **across the finger width** (coaxial with the knuckle pin), with one lobe seated on the segment's own pin bore and the other reaching into the neighbouring segment (MCP → palm knuckle, PIP → fingertip), bridging the gap. In `print_layout` the ten connectors lay out flat on a plate (`hinge_plate()`) for printing in flexible filament (Filaflex/TPU).
feat: New `show_hinges` toggle + `color_hinge` colour, a dedicated **Flexy joints (plate)** printable part (`show_hinges` toggle) for isolated STL export, and full EN/PT captions + help. Verified end-to-end: default, small-child (60 mm palm / 5 mm joints / short fingers) and isolated-part exports all render the connectors correctly sized and placed.

## v14.33.0 — 2026-07-09

fix: **Newly-added/edited models now appear for returning browsers.** The model-selection grid (`screens.js`) and the editor config load (`app.js`) fetched `models/models-config.json` with default caching and no `?v=` cache-buster, so a browser holding a cached copy kept showing the old model list — the freshly-deployed Cyborg Beast card was invisible until a hard refresh. Both fetches now use `{ cache: 'no-cache' }` to revalidate against the server (cheap 304 when unchanged, fresh JSON when models change). Bump `index.html` JS cache-buster to 14.33.0.

## v14.32.0 — 2026-07-09

feat: **Integrate the original Cyborg Beast hand** (MakerBlock / e-NABLE — Chicago-screw + elastic-cord mechanical build, distinct from the flexible-joint Flexy Beast). The original palm, two-segment fingers and thumb geometry (`cyborgpalm001` / `cyborgfingermid002` / `cyborgfingertip002`) are wrapped in a new anthropometric parameter layer in `models/active/cyborg-beast/cyborg_beast.scad` and registered as model `cyborg_beast`.
feat: Anthropometric sizing calibrated by measuring the original geometry — whole hand scales by the Cyborg Beast formula `(palm_breadth_mm + 5) / 55`, while each finger is driven independently to its absolute MCP-to-tip length via the design's native `len` lever (inverting the measured reach curve `R = 60.85 + 1.584·len` for len ≥ 0, `+ 1.328·len` for len < 0), with `len` clamped to a print-safe range. Thumb length driven by a uniform, gap-free scale of its two-segment sub-assembly. UI-controlled laterality (`mirrored`, `role:"laterality"`).
feat: Per-part colour customiser (palm + per-segment finger/thumb colours) baked into the 3MF multi-material export, plus a flat print-bed `print_layout` and per-part `show_*` visibility toggles / `parts` map for isolated STL export — matching the Flexy Beast feature set. Full EN + PT captions/help.
chore: Add `tests/cyborg_export.spec.js` — Playwright e2e over the real WASM pipeline: per-segment colour → coloured 3MF (verifies the chosen `displaycolor` is baked in) and a whole-hand combined export carrying all 11 part colours.
chore: Exclude scratch/in-progress build artifacts (`_assembly.*`, `*_preview.png`, `assemblage-*.jpg`) from deploy (`deploy.sh` EXCLUDES) and git (`.gitignore`) so merged-assembly renders and reference photos never ship to prod or get committed. Bump `index.html` JS cache-buster to 14.32.0.

## v14.31.0 — 2026-07-09

refactor: **PEC PHOENIX HAND assembly — gauntlet placed by its hinge.** The gauntlet now rotates about its boss/hinge line instead of its own origin, so `GAUNT_POS` (where the hinge sits — default the measured wrist-ear centre) and `GAUNT_ROT` (forearm tilt about that hinge) are independent — changing the cuff angle no longer slides the hinge off the wrist ears. Added measured `GAUNT_HINGE_LOCAL = [0, 79.005, 1.9]` (boss centre in the gauntlet's own frame) and place it via `translate(GAUNT_POS) rotate(GAUNT_ROT) translate(-GAUNT_HINGE_LOCAL)`.

## v14.30.0 — 2026-07-09

feat: **PEC PHOENIX HAND assembly — hinge pins at every joint.** Added the snap-pins in their measured holes, sized per class from the exploded reference photo (`unlimbed_phoenix_hand/assemblage-main-phoenix-eclatee-fabrication-3d.jpg`): 4 MCP (palm↔proximal) + 4 PIP (proximal↔distal) + 2 thumb (MCP+PIP) at Ø4.5, and 2 bigger wrist pins (palm↔gauntlet) at Ø6 with green dome washers. Each pin is drawn in the SAME placed frame as its digit (a `snap_pin_x()` along the local joint axis), so it sits in the hole and follows the finger through splay/flex/roll. New tunables: `PIN_DIA_*`, `PIN_LEN_*` (per class), `PIN_SHOW_MCP/PIP/THUMB/WRIST` (hide individually), `PIN_OFF_*` (nudge each), `SHOW_WASHERS`; wrist-ear pin centres `WRIST_PIN_A/B` measured at (±, −38, 8).

## v14.29.0 — 2026-07-08

feat: **PEC PHOENIX HAND assembly — full per-distal controls + un-invert default.** Each fingertip now has independent `DIST_OFF[i]` (position nudge x,y,z mm) and `DIST_ROT[i]` (rotation x=tilt/flex, y=roll, z=yaw), plus `TH_DIST_OFF`/`TH_DIST_ROT` for the thumb — all pivoting about the PIP joint so the fork stays mated. Default `DIST_ROT` roll is set to `y=180`, which flips the previously up-curling (inverted) tips down toward the grip. `place_digit()` now takes the offset + rotation and applies both about the PIP. (Trade-off noted for tuning: the 180° roll moves the flexor side dorsal; set `y=0` + a small `x` tilt to keep the flexor palmar instead.)

fix: **thumb orientation — fins now dorsal, aligned to the palm thumb-mount fin.** `TH_ROT` default changed to `[30,35,-120]` so the thumb proximal's clip fins sit dorsal and continue the palm mount fin (measured at (34,-7.5,12.5), tilt45/yaw-40) instead of lying on their side; nudge `TH_ROT` to perfect the fin-to-fin alignment.

feat: **thumb roll-about-own-axis (`TH_ROLL`).** New `TH_ROLL` spins the whole thumb about its own long axis (mirroring the unlimbed Phoenix proximal's 180° fin-up flip) so its clip fins can be rolled to face dorsal and continue the palm mount fin, independently of where `TH_ROT` points the thumb. `place_digit()` gained an optional `roll` param (innermost rotate about local +Y at the MCP, which sits on that axis so the joint stays seated); fingers pass `roll=0`.

## v14.28.0 — 2026-07-08

feat: **PEC PHOENIX HAND — assembled view of the parametric reconstruction.** New `models/active/pec_phoenix_hand/_assembly.scad` seats every parametric part on its **measured** mating feature: the four proximals drop onto the palm's measured finger-ring pins (index/middle at Y40, ring Y36, pinky Y30), each fingertip's PIP fork hole meets the proximal PIP (23.03 mm span), the thumb rides its measured pivot bore (28.7, −9.6, 5.8), and the gauntlet hinges at the wrist ears. All placement lives in a top **TUNABLES** block (per-finger KX/KY/SPLAY/FLEX, distal size + PIP flex, thumb pose, gauntlet pose, per-part visibility/colour); the **MOUNTS** block holds the measured hole positions read out of the part files. The palm is `include`d (its modules need file-globals + a ghost STL that a bare `use` drops), the proximal/distal/gauntlet parts come in via `use<>`; BOSL2's special-var defaults arrive through the palm's own include. Added minimal assembly entry points to the parts: `arm_guard()` wraps the gauntlet's top-level render, `distal_std/short/thumb()` wrap the fingertip sizes, and both the gauntlet and palm standalone renders are now suppressed by a `no_assembly` guard so a driver can drive them. NOTE: renders in desktop OpenSCAD only — the palm/rings/thumb clip to a local ghost STL and three parts pull in BOSL2, so this is **not yet browser-WASM portable** (that, plus anthropometric params + `models-config.json` wiring, is the next phase).

docs: **print-validation per-part 3MF split (Flexy + Paraglider).** Each combined print plate now also ships every printable part as its own colored, bed-seated 3MF under `docs/print-validation/<model>/<age>/parts/` — matching the platform's per-part export modal. Parts are isolated by their toggles, **centered on the bed and dropped to Z=0** (the same drop-to-bed the frontend does), and exported with the per-part colour baked as a 3MF material. Flexy Beast = 12 parts (palm, gauntlet, base+tip of each finger/thumb); Paraglider = 7 parts (palm, 5 fingers, pins); Phoenix was already per-part. Total print-validation set is now 116 `.3mf` files (8 combined plates + 76 individual parts + 32 Phoenix). README updated.

## v14.26.0 — 2026-07-08

docs: **print-validation 3MF set — AI-sized age variations across all three models.** New `docs/print-validation/` follows up `ai_anthropometric_validation.md` by closing the loop from AI numbers to print-ready 3MF. The same Brazilian-male archetype prompt ("Homem 28") is declined into four age groups (`child_8`, `teen_15`, `adult_28`, `elderly_70`) and run through the **live pipeline** (frontend prompt reconstruction → authenticated `POST /api/ai/suggest`, `claude-sonnet-4-6`, dataset grounding active — all 12 runs `grounded: true`) → OpenSCAD 2026 3MF export (mm units, per-part colours as materials). 40 `.3mf` files with `.png` previews: Flexy Beast (whole print plate ×4), Paraglider (disassembled plate ×4), UnLimbited Phoenix (8 parts ×4). Each folder keeps its `params.json` (AI suggestions + grounded flag) and `prompt.txt`. Phoenix `child_8` correctly floors at 82 mm with no `HandPerc_override` bypass (confirms the v14.18.0 fix); exported palm bbox verifies uniform scale (82→90 mm ratio = 1.098 = HandPerc 90/82).

## v14.25.0 — 2026-07-08

feat: **assembled-view render of the UnLimbited Phoenix hand.** `models/active/unlimbed_phoenix_hand/_assembly.scad` places every component in one scene (thermoform palm, four two-segment fingers, thumb, MCP/PIP pivot pins, wrist hinge pins, and the flat gauntlet). Exported presentation meshes committed alongside it: `_assembly.stl`, `_assembly.3mf`, and a `_assembly.png` hero render. Note the STL/3MF are visual triangle-soup meshes, not print-ready solids — the source palm mesh (`Phoenix_Thermo_Palm_2`) is non-watertight, so a normal OpenSCAD export drops it; the committed mesh merges the palm's raw triangles with the rest of the assembly in world coordinates.
fix: **Phoenix assembly finger + thumb joints rebuilt from measured pin holes.** Every joint hole was located in the meshes (enclosed-void flood-fill) and the parts placed so the holes coincide. Proximal phalanges flipped 180° about their long axis so the fork **fins point up** (dorsal) while both pin holes stay on the axis and the tall knuckle (higher part) sits at the MCP/palm end. Fingertips nudged (`PIP_DY/DZ`) so each **distal back hole meets the proximal front (PIP) hole**. Fingers placed so each **proximal back (MCP) hole seats in the palm knuckle pin hole** (measured `(80,-63,5.9)(65,-63,5.9)(55,-63,5.9)(42,-67,5.9)`): `KX=[80,65,55,42]`, `KY=[-66.2,-66.2,-66.2,-70.2]`, `KZ=4.2`. Thumb seated so its MCP hole meets the boss pin hole `(94.6,-111,17)`: `TH_POS=[91.2,-110,16.5]`. Visual pivot pins moved onto the measured hole positions so they run through the joints.
chore: bump front-end `?v=` cache-buster in `index.html` to `14.25.0` to match `package.json`.

## v14.24.0 — 2026-07-01

fix: **cache-bust front-end JS on deploy.** Returning browsers were serving stale cached copies of the static scripts (no `?v=` query, no `Cache-Control` header), so newly deployed strings didn't appear — e.g. the new Colors tab rendered its raw i18n key `cfg.tabColors` because the cached `translations.js` lacked the translation. All local `<script>` tags now carry a `?v=<version>` query (`translations.js`, `i18n.js`, `auth.js`, `footer.js`, `screens.js`, `app.js`); bump it to match `package.json` on each release so a deploy always invalidates the cache. Documented as a `/cpd` safety check. (Production content was already correct — this was purely a client caching problem.)

## v14.23.0 — 2026-07-01

feat: **dedicated Colors tab + per-part colours.** The configuration card gains a **Colors** tab between Parameters and Saved (order: AI Assistant → Parameters → Colors → Saved). `type: "color"` params are split out of the Parameters list and rendered as swatches in the Colors tab, one per printable part; the Parameters tab keeps everything else. Empty/idle states handled (no model → prompt; model without colours → notice). i18n en+pt (`cfg.tabColors`, `cfg.colorsIntro`, …).

feat: **Flexy Beast is now colourable per printable part**, including per finger *segment* (proximal/base and distal/tip separately) — palm, forearm gauntlet, and base+tip of every finger and the thumb (12 colours). Each part's geometry is wrapped in `color()` in both the assembled and print-bed layouts (`fingerlayout` gains `baseCol`/`tipCol`; `handlayout`/`printlayout` pass per-part colours), so the choice shows in the preview and is baked into the 3MF export as a distinct material per part. The silicone grip pad keeps its own `pad_color` overlay (nested `color()` overrides the tip colour on the pad region only). Paraglider was already per-part (7 colours); Phoenix has no printable parts. Verified with the OpenSCAD CLI (both layouts compile manifold with 12 distinct COFF colour groups) and a Playwright end-to-end test (Colors-tab order + 13 swatches + a distal-segment colour baked into the exported 3MF).

## v14.22.0 — 2026-07-01

feat: **colour customiser** — the per-part colour parameters (Paraglider: palm + 5 digits + pins; Flexy Beast: grip pads) now render as native colour **swatches** instead of raw hex text fields, with a live hex readout. Picking a colour flows through the existing parameter pipeline, so the 3D preview repaints immediately and the choice persists in saved configs. Introduces a `type: "color"` parameter kind (`generateParameterControl` renders `<input type="color">`; `updateEditor` quotes it as a SCAD string). Colour params are excluded from the AI sizing list (cosmetic + user-owned), mirroring the laterality exclusion. Captions updated (`preview color` → `colour (preview + 3MF)`), including the Flexy Beast pad help that previously claimed "no effect on the printed STL".

feat: **colours are baked into 3MF export.** 3MF export now renders in colored OFF (COFF) rather than binary STL, so each face's `color()` choice becomes a 3MF material: distinct colours form a `<basematerials>` palette and every triangle carries a `p1` index into it — the core-spec mechanism a multi-material slicer (Bambu/Orca/Prusa MMU) reads to assign a filament per colour. Per-part whole-model exports are rendered, bed-seated, and merged part-by-part in COFF (matching the STL path). The OpenSCAD worker call is refactored into a shared `_runExportWorker(code, out, format)` behind `_renderStlFromCode`/`_renderOffFromCode`. Verified: generated colour 3MF is well-formed OPC XML, `unit=millimeter`, materials round-trip, and loads watertight/seated in trimesh. (Supersedes v14.21.0's uncoloured STL→3MF converter.)

## v14.21.0 — 2026-07-01

feat: export to **3MF** alongside STL. The export modal now has a format selector (STL / 3MF, 3MF marked recommended); every model routes through the modal so the choice is always available (models with no printable `parts` show a single pre-checked "Whole model" row). 3MF is the print-ready modern format — it embeds explicit **millimetre units**, so slicers import at the correct scale instead of guessing from a unitless STL (a real risk for a clinical device). Implemented client-side with zero new dependencies, converting the positioned mesh to an OPC (ZIP) 3MF package at the download step. Multi-part selections zip per-file exactly as before. The "Export STL" button is now labelled "Export"/"Exportar" (i18n en + pt).

## v14.20.0 — 2026-06-29

refactor: make the AI sizing prompt model-driven — first structural step of the universalization roadmap (towards limbs beyond the hand). The hand-specific domain guidance (canonical measurement fields, finger-proportion hint) and the limb noun were hardcoded in `app.js`; they now come from two per-model fields in `models-config.json`: `limb` (e.g. `"hand"`) and `aiGuidance`. The prompt intro reads "prosthetic &lt;limb&gt; model" from config, and the domain-guidance line is injected from the model's `aiGuidance`, so a future lower-limb model (foot/leg) carries its own vocabulary and hints without any code change. Hand-sizing quality is unchanged (verified: same applied parameters, laterality still omitted, grounding intact). Roadmap documented in `docs/ai_anthropometric_validation.md` §9.1.

## v14.19.0 — 2026-06-29

fix: limb side (left/right) is now controlled solely by the user in the UI — the AI no longer infers or overrides it. A UCD evaluation found the AI emitted `mirrored=true` (right hand) regardless of the requested side, so explicit left-hand requests silently produced a right hand (reproducible 4/4) — a safety defect a layperson can't catch until printed. Handedness parameters are now tagged `role: "laterality"` in `models-config.json` (`mirrored` on Flexy Beast & Paraglider, `LeftRight` on Phoenix); `app.js` excludes them from the AI's suggestible parameter list, injects the user's chosen side into the prompt as a fixed fact, and defensively drops any laterality key from `applySuggestions`. Verified: the AI now omits `mirrored` in 9/9 runs (incl. UI-says-left / text-says-right conflict). Designed generically as **laterality** (not "handedness") so it already applies to any future paired limb (arm, foot, leg). The prompt intro was also de-specialised from "prosthetic hand" to "prosthetic" toward broader limb support.

## v14.18.0 — 2026-06-28

fix: the UnLimbited Phoenix Hand print scale can no longer drop below the supported 100% (≈82 mm palm). `HandPerc_override` has a declared range of `[0:160]`, but only `0` (auto) and `100–160` (direct scale) are meaningful — the `1–99` band was a dead zone that bypassed the floor that `palm_breadth_mm` (clamped to 100–160%) enforces. During the AI-sizing simulation the model returned `HandPerc_override = 76` for a child, scaling the Phoenix mesh to 76% (62 mm) — below the minimum the mesh supports, and inconsistently with the woman profile (floored to 100%). Both scale paths in `UnLimbitedPhoenix.scad` are now clamped to 100–160%, so neither an auto-derived small breadth nor a manual override can go sub-100%. Verified: override 76→100% (82.17 mm), 0→82.17 mm, 130→130% (106.8 mm). Found and documented via `docs/phoenix-ai-sim/`.

## v14.17.0 — 2026-06-28

fix: the Paraglider · Hand **Reborn palm** (the default `palm_style`) now resizes to `palm_breadth_mm`. It was frozen at the 83 mm "medium" size for every patient: `scaled_palm()` lives in `paraglider_palm_left.scad`, which is pulled in with `use` (lexically scoped), so it read that file's hardcoded `overall_scale = 1.25` and ignored the anthropometric `overall_scale = palm_breadth_mm / 66.4` computed in the main file. The fingers were unaffected (they receive their scale as a module argument), so a child-sized configuration produced child fingers on an adult palm. Fix re-applies the intended scale at the Reborn call site (`scale(overall_scale / 1.25) scaled_palm()`); verified the palm now scales (breadth 62→84.9 mm, 83→113.7 mm unchanged, 96→131.5 mm) with L/breadth constant. The UnlimbitedV3 palm was already correct (`pg_v3palm.scad` is `include`d). Found via the AI-sizing→STL export simulation (`tests/paraglider-ai-sim/`).

## v14.16.0 — 2026-06-28

fix: AI grounding now picks the right anthropometric population profile. `findBestProfileMatch` (server/services/profileMapping.js) previously anchored almost every patient on *ANSUR I Male 50th Percentile* — the male gender token `'m,'` was a substring of the units `"mm,"`/`"cm,"`, so any description containing a measurement was read as male, and gender/age parsing was English-only. Tokens are now matched on Unicode word boundaries and are multilingual (EN/PT/ES); age parsing understands "anos"/"años"; numeric `age_group` values ("7", "18-30", "80+", "Adult (Military, 17–40)") are bucketed to child/adult/elderly with numeric proximity, so a 7-year-old maps to the age-7 children dataset and a woman to a female dataset.
- feat: optional LLM-based extraction of patient `{gender, age}` (`extractPatientAttributes` in aiService.js, via `claude-haiku-4-5`) anchors grounding for free-text/multilingual descriptions. It runs only when the deterministic parser leaves a gap, and degrades gracefully (falls back to text parsing) on any error or missing key.
- test: add hermetic unit tests for the matcher (`test/profileMapping.test.js`, run with `npm run test:unit`) covering the units-as-male regression, multilingual gender/age parsing, age-group bucketing, and hint overrides.

## v14.15.0 — 2026-06-24

feat: "Export all" STL now lays every part flat on the print bed instead of in the assembled hand pose. Models that render an assembled hand for the on-screen preview (Flexy Beast, Paraglider) switch to a flat print-bed layout only when exporting — the preview stays assembled. Each exported part is seated on Z=0 (the exporter drops every STL's lowest point to the bed), and the "Whole model" single file is built by rendering each part on the bed and merging them into one co-planar plate, so nothing floats or prints as supports-heavy assembled geometry.
- feat: Flexy Beast gains a `print_layout` mode (`printlayout()`) that spreads the palm, gauntlet, four fingers (base + tip), and thumb side-by-side in their native print orientations.
- fix: Paraglider print-bed layout no longer flips finger parts below the bed (parts now rest co-planar on Z=0) and now emits the pivot pins laid flat, so the "Pivot pins" part exports geometry instead of an empty file.
- feat: models can declare an `exportLayout` map in `models-config.json` (e.g. `{ "print_layout": true }`) that the exporter applies to every exported part.
- docs: document the cPanel/Passenger deployment workflow (`./deploy.sh deploy`, dry-run, what needs a cPanel restart, the server-managed `.htaccess`/WASM headers) in `CLAUDE.md` and `README.md`.

## v14.14.0 — 2026-06-22

feat: the appbar help (?) button now opens an anchored help popover instead of a blocking `alert()`. The panel shows a numbered 6-step getting-started walkthrough (pick a model → adjust parameters → AI assistant → import measurements → render & export → save), plus a "More help" section with collapsible documentation: an anatomical field guide (palm/finger/gauntlet measurements) and keyboard/viewer controls, and a contact-support link. Closes on outside click or Esc; fully localised in EN + PT.

## v14.13.1 — 2026-06-16

fix: help button icon now renders its question-mark dot. The appbar help icon (Feather `help-circle`) draws its dot as a zero-length `M12 17h.01` stroke, which is only visible with `stroke-linecap="round"`. The SVG was missing that attribute, so the dot disappeared and the icon looked incomplete. Added `stroke-linecap="round" stroke-linejoin="round"`.

## v14.13.0 — 2026-06-16

fix: Flexy Beast per-part STL export no longer includes the gauntlet in every part. The gauntlet is gated by `show_gauntlet` in the SCAD but was absent from the model's `parts` list, so the per-part export override (which only toggles off variables belonging to a declared part) never set it false — every exported finger/palm STL silently bundled the forearm cuff. Added the gauntlet as its own printable part (`show_gauntlet`), which both excludes it from the other parts' exports and lets it be exported on its own. Verified: palm-only export drops from ~20.6k to 14.4k facets (gauntlet gone); gauntlet-only export is 6.3k facets.

## v14.12.0 — 2026-06-16

feat: add transactional email subsystem (SMTP via nodemailer) powering three flows — self-service "forgot password" (public, non-enumerating `POST /api/auth/forgot-password` that emails a reset link reusing the existing token machinery), email verification on self-service registration (`POST /api/auth/verify-email` + `POST /api/auth/resend-verification`), and an admin "account created" notification when a user is created from the admin panel. New `server/services/emailService.js` lazily builds the SMTP transport and degrades to a logged no-op when SMTP is unconfigured, so nothing breaks until credentials are supplied. Frontend gains a Forgot-password view, a verification view, and handling of `/reset?token=…` and `/verify?token=…` email links (token auto-filled, stripped from the URL); 12 new EN/PT i18n keys (parity 308=308).
feat: email verification is non-breaking and opt-in — new `users.email_verified` column + `email_verification_tokens` table; a migration grandfathers all existing and admin-created accounts to verified. Login enforcement is gated behind the new `REQUIRE_EMAIL_VERIFICATION` env flag (default off): when off, unverified users can still sign in; when on, only unverified self-service registrations are blocked.
chore: add `nodemailer` dependency; document `SMTP_HOST`/`SMTP_PORT`/`SMTP_SECURE`/`SMTP_USER`/`SMTP_PASS`/`MAIL_FROM`/`APP_BASE_URL`/`REQUIRE_EMAIL_VERIFICATION` in `.env.example`; startup log now reports whether SMTP is enabled.

## v14.11.0 — 2026-06-16

refactor: consolidate the Paraglider family from 7 dropdown entries into a single `Paraglider · Hand` model with the variations as in-model options. A new `component` selector (Hand / Tensioner Box / Thermo Gauntlet / UnLimbited Arm) and `palm_style` selector (Phoenix Reborn / Unlimbited v3) replace the separate entries. Implemented by namespacing each component's OpenSCAD source (every internal identifier prefixed, top-level geometry wrapped into a `*_main()` module) so the otherwise-colliding near-duplicate files coexist in one dispatcher via `include`; the bundles are driven by the Hand's shared anthropometric inputs. New `scripts/namespace_scad.py` tool generates the bundles. Each component verified byte-faithful against its standalone render (Box 3246, Gauntlet 2230, Arm/Cuff 10686 facets — exact) through the app's injection + dependency pipeline, zero scoping warnings. Adds `Component` and `Arm` parameter groups (EN/PT). The two integrated-tensioner palm variants were dropped (tensioning is covered by the Tensioner Box component); removed the now-unused `models/active/paraglider/` sources.

## v14.10.0 — 2026-06-15

feat: integrate the Paraglider (Flexible Flyer) prosthetic family by Marcus Mendenhall (parametric Phoenix v2 / UnLimbited v3 / Phoenix Reborn remix using commercial metal-pin joints). Adds 7 models: `paraglider_hand` (the unified palm+fingers hand — re-activated from inactive/, its missing `palm_left_v2_nobox.stl` supplied, wired into models-config.json with the canonical anthropometric params, per-finger scaling, assembled/print-layout views and `show_*` part toggles), plus `paraglider_palm_v3`, two integrated-tensioner palm variants (Reborn + Unlimbited v3), `paraglider_tensioner_box`, `paraglider_thermo_gauntlet`, and the elbow-powered `paraglider_unlimbited_arm`. Variant palms/accessories live under `models/active/paraglider/` and derive a uniform print scale from a canonical `palm_breadth_mm` (REF anchored to each palm's 1.0× width) with a `scale_override`; the arm keeps its native `HandLen` (mm). New `Engraving` parameter group (EN/PT). All 7 verified rendering under the manifold backend via the app's parameter-injection + dependency-mount pipeline.
fix: source patch — removed an upstream double-comma `[[..],,[..]]` array-literal syntax error (rejected by current OpenSCAD) from the four Paraglider palm files; converted the v3 palm mesh from `.3mf` to `.stl` for WASM import safety.
docs: rewrote docs/paraglider.md to reflect activation + the variant/accessory entries, and corrected the stale claim that the WASM build cannot parse the `each` keyword (the vendored build is OpenSCAD 2025.03.25, which supports it).
chore: removed the redundant `models/inactive/paraglider_hand/` copy now that the model is active.

## v14.9.0 — 2026-06-15

feat: complete the European-Portuguese (pt-PT) translation pass. The admin panel's toast/confirmation messages now go through `t()` with `admin.t*` keys, and the entire anthropometric profile modal (section headings, field labels, hint spans, select options, placeholders, and action buttons — 65 `anth.*` keys) is translated via `data-i18n`/`data-i18n-html`/`data-i18n-placeholder` and switches live with the language selector
docs: add `README.pt.md` — full European-Portuguese README, cross-linked with the English README via a language switcher line

## v14.8.0 — 2026-06-15

feat: European-Portuguese (pt-PT) content. The six footer pages (Help Center, Documentation, Tutorials, Privacy Policy, Terms of Service, Accessibility) now have linked PT translations created via the CMS (`scripts/seed-content.js`), so PT visitors read them in Portuguese. All 37 Flexy Beast parameter ⓘ help tooltips gained `help_pt` translations in `models-config.json`

## v14.7.0 — 2026-06-15

docs: accuracy pass on the remaining docs — bump the Node requirement to ≥22 across DEPLOYMENT.md, DEPLOY-QUICKSTART.md, QUICK-START.md and OVERVIEW.md; replace `better-sqlite3` references with `node:sqlite` (DEPLOYMENT.md note, OVERVIEW.md stack table, TROUBLESHOOTING.md); flag the live cPanel/Passenger path in DEPLOY-QUICKSTART; correct the native-module guidance (bcrypt prebuilt, SQLite built into Node) and the model list (Phoenix added, Paraglider under inactive/)

## v14.6.0 — 2026-06-15

docs: bring README.md up to date — add the UnLimbited Phoenix Hand model (Paraglider kept, marked returning), bump the Node requirement to ≥22 (node:sqlite, no native compile), add the multilingual (EN/PT) and editable footer/content-pages (CMS) features, refresh the deployment notes (cPanel/Passenger, bcrypt prebuilt) and project structure (i18n/footer/markdown/page.html, content route, seed-content.js, models active/inactive), and document the `/api/content/*` endpoints

## v14.5.0 — 2026-06-15

docs: add the live deployment URL (handfab.pedrocandeias.net) to the top of README.md

## v14.4.0 — 2026-06-15

feat: multilingual content pages (CMS). Each language is its own linked page record — the `pages` table gains `language` + `translation_group` columns (auto-migrated on startup; existing pages become their own en group). New `POST /api/content/pages/:id/translate` clones a page into a chosen language, pre-filled from the source, that the admin then edits. The public viewer (`/pages/<slug>?lang=xx`) resolves to the visitor's-language translation within the group, falling back to the original. `page.html` gains a language switcher and re-fetches on change; the admin Pages tab shows a Lang column, per-row "+ LANG" Translate buttons, and a language field on the page form

## v14.3.0 — 2026-06-15

feat: integrate the Team UnLimbited Phoenix Hand V1.0 as a second prosthetic model (`unlimbed_phoenix_hand`). The Phoenix ships as fixed STL-derived meshes, so it exposes a uniform print scale rather than per-finger parameters. To keep it in the anthropometric pipeline, the .scad now derives `HandPerc` from a canonical `palm_breadth_mm` input (REF_PALM_BREADTH = 82 mm at 100%, clamped 100–160%), with an optional `HandPerc_override` for direct scale control. A `part` enum selects which of the 8 printable pieces (Palm, Fingers, Phalanx, Pins, Tension Box, Tension Pins, Gauntlet, Jig) to preview/export. Full EN/PT labels, captions and help text; manifold-backend render verified for all parts.
fix: app.js now quotes string-valued `enum` parameters when injecting them into SCAD source (previously only `string`-type params were quoted), so string enums like the Phoenix `part`/`LeftRight` selectors emit valid OpenSCAD (e.g. `part = "Palm";`).

## v14.2.0 — 2026-06-15

feat: translate the configurator's model + parameter text (EN/PT). models-config.json gains per-language fields (`name_pt`, `description_pt`, and per-parameter `label_pt`/`caption_pt`); app.js reads the active-language field via a `locField()` helper and translates group headings through translations.js. Covers the Flexy Beast model name/description, all 37 parameter labels and captions, and the 6 group headings. The detailed ⓘ help-tooltip paragraphs (`help`) still fall back to English — `help_pt` is supported and can be filled in incrementally

## v14.1.0 — 2026-06-15

feat: extend translations (EN/PT) to the admin panel — app bar, tabs, Users tab (form, table, role/status badges, action buttons), Tech Assignments, and the Footer & Pages editor, plus a switcher in the admin bar and live re-render on language change. ~80 admin keys added. Not yet translated: transient toast messages and the detailed anthropometric measurement form labels (English fallback)

## v14.0.0 — 2026-06-15

feat: the platform is now translatable, with a language switcher (English + Portuguese). New lightweight i18n core (`i18n.js` + `translations.js`): static strings use `data-i18n`/`data-i18n-placeholder`/`data-i18n-title` attributes, JS-generated UI uses a global `t(key, vars)`, and the active language is detected from the browser and persisted in localStorage. Switchers sit in the app bar and on the login page; changing language re-renders the dynamic UI in place (no reload, editor state kept)
feat: this first pass covers the main app — login/setup, dashboard, the configurator (tabs, AI panel, buttons, saved-config controls, "Enable"), profile, and the user menu/greeting. Admin panel, parameter tooltips/model descriptions, and CMS content pages are not yet translated (English fallback)

## v13.11.0 — 2026-06-15

docs: rewrite the Privacy Policy and Terms of Service pages to a broad, open-source "use at your own risk / no warranty / no liability" stance — removed all jurisdiction/legal-entity placeholders. Kept the strong "not a medical device" disclaimer. Updated `scripts/seed-content.js` and re-seeded the live pages

## v13.10.0 — 2026-06-15

fix: the bulk anthropometric CSV importer now keeps age groups as distinct profiles. The `group_name` previously omitted `age_group`, so same-population age bands collapsed to one arbitrary band; it now folds in a normalised age label (e.g. "…, age 19–30 (Country)"). Importing `multi_population_hand.csv` yields ~97 profiles instead of 27 — notably preserving a full pediatric series (Dutch children, ages 2–12) that was being silently dropped

## v13.9.0 — 2026-06-15

fix: raise the JSON request body limit from 1 MB to 8 MB so the admin "Import CSV" bulk anthropometric import works for the bundled `multi_population_hand.csv` (~1.1 MB), which previously exceeded the limit and 413'd

## v13.8.0 — 2026-06-15

fix: the admin "New Profile" (and Edit) anthropometric modal now actually opens. `openNew()`/`openEdit()` show it by adding the `active` class, but there was no `#anthro-modal.active` CSS rule, so it stayed `display:none`. Added `#anthro-modal.active { display: flex; }`

## v13.7.0 — 2026-06-15

feat: show the thermoformable palm-interior mesh by default on the Flexy Beast model — `show_thermoform` default flipped to `true` in both `flexy_beast.scad` and `models-config.json`

## v13.6.0 — 2026-06-15

feat: populate the footer content pages — Help Center, Documentation, Tutorials, Privacy Policy, Terms of Service, and Accessibility now have real Markdown content (added via the new idempotent `scripts/seed-content.js`). The footer Contact column is slimmed to a single email (`mailto:hello@handfab.pedrocandeias.net`) plus a GitHub link; Support/Legal columns link to the pages. Legal pages are general-purpose drafts with bracketed placeholders for jurisdiction/entity — they need legal review

## v13.5.0 — 2026-06-15

chore: remove the printed wrist hinge rod from the Flexy Beast model — dropped the `wrist_pin()` part and its `show_wrist_pin` toggle (also removed from `models-config.json`). The wrist pivot holes, clearance, and strap-flap splay remain, so the gauntlet still articulates on a pin/bolt the user supplies (hole sized by `wrist_pin_dia`)

## v13.4.0 — 2026-06-14

chore: move the gauntlet STL→SCAD reconstruction sources out of the platform model dir into `models/reconstruction/flexy_beast/` (source mesh, organic + primitive variant `.scad`, extracted profile/strap data, exported STLs, build artifacts, + a README). `models/active/flexy_beast/` now holds only the platform file `flexy_beast.scad` (which already inlines the finished gauntlet)
chore: exclude `models/reconstruction/` from deploy (`deploy.sh`) — dev-only material, not shipped to the live platform

## v13.3.0 — 2026-06-14

fix: allow Google Fonts under the CSP — `style-src` now includes `https://fonts.googleapis.com` and a new `font-src` allows `https://fonts.gstatic.com`. Node/Passenger-served pages (e.g. the `/pages/<slug>` viewer) now load the DM Sans brand font instead of falling back to a system font

## v13.2.0 — 2026-06-14

feat: make the Flexy Beast wrist an articulating hinge. Added a printed wrist pin (cap-headed rod) that press-fits the palm wrist fins and lets the gauntlet rotate on it; the gauntlet strap flaps now auto-splay outward to sit just inside the fins for a snug pivot, and their pin holes are drilled round in assembly space (with clearance) so the cuff swings freely
feat: new `[Wrist Hinge]` parameters in `models-config.json` — `show_wrist_pin`, `wrist_pin_dia` (defaults to the finger joint pin size), `wrist_pin_clearance`, `strap_splay_adjust`
refactor: the palm wrist pin hole (`hardwarecutouts`) now sizes to `wrist_pin_dia` instead of a fixed 4 mm

## v13.1.0 — 2026-06-14

feat: add a parametric forearm gauntlet (wrist-powered tensioner cuff) to the Flexy Beast model, reconstructed from `Normal_Gauntlet_w_Tensioner.stl`. Built entirely from primitive shapes — a tapered oval half-pipe tunnel (hull of elliptical discs, shelled, palmar opening cut by a box) plus the tensioner boss, triangular crenellation slots, dorsal holes, and two distal straps
feat: new `[Gauntlet]` parameters exposed in `models-config.json` — `show_gauntlet`, `gauntlet_width_mm` (forearm socket width), `gauntlet_length_mm`, `gauntlet_wall_mm`, `gauntlet_pos_adjust`. The cuff is a separate printed part positioned at the wrist, scaled to its own forearm dimensions (independent of knuckle breadth), with strap-tip pivot holes aligned to the palm's wrist hinge pin axis so it pins on as a hinged forearm piece
chore: gauntlet modules use only core OpenSCAD primitives (no BOSL2) and are `g_`-prefixed/`$fn`-scoped, keeping `flexy_beast.scad` OpenSCAD-WASM compatible and isolated from the hand geometry

## v13.0.0 — 2026-06-14

feat: admin-managed footer + content pages (mini-CMS). New admin "Footer & Pages" tab lets admins edit the footer (brand, tagline, copyright, and add/remove/reorder columns + links, each link → an internal page or external URL) and create/edit/delete Markdown content pages
feat: pages render at clean URLs `/pages/<slug>` via a new `page.html` viewer with a small safe Markdown renderer (`markdown.js`); the footer renders dynamically from `/api/content/footer` (`footer.js`) on every page, with the original markup as fallback
feat: clean URL for the admin panel — `/admin` (drop `.html`); internal links updated (`admin.html` → `/admin`, `index.html` → `/`)
feat: new `server/routes/contentRoutes.js` — `GET /api/content/footer` (public) / `PUT` (admin); `GET /api/content/pages` (admin list), `GET /api/content/pages/:slug` (public published), `POST/PUT/DELETE` (admin). New `site_settings` and `pages` tables in schema.sql (auto-created on startup)

## v12.6.0 — 2026-06-14

fix: the footer now appears on the configurator (`/edit`) and every in-app screen. Replaced the per-screen footers (which existed on selection + profile but were missing from customization) with a single shared footer rendered at the `#app-shell` level. The login/logout page keeps its own footer

## v12.5.0 — 2026-06-14

feat: the model name + description in the configurator is now a collapsible accordion (native `<details>`, closed by default) placed above the tab list, so it's available from all three tabs (AI Assistant, Parameters, Saved) instead of only Parameters. Chevron rotates when open; all element IDs preserved so the populate logic is unchanged

## v12.4.0 — 2026-06-14

feat: soften the Saved Configuration Save/Delete buttons in the configurator — muted emerald `#2bb673` and muted rose-red `#d9596a` (down from the saturated `#22c55e`/`#d4183d`), to sit better with the design. Scoped to `#config-save-btn`/`#config-delete-btn` so admin.html's green buttons are unaffected

## v12.3.0 — 2026-06-14

feat: the URL now reflects the active screen — `/dashboard` (model selection), `/edit` (configurator), `/profile`. Navigating updates the address bar via the History API, and browser back/forward switches screens. On a cold load / deep link the app lands on `/dashboard` (the editor and profile can't be restored from the URL alone). `show()` now syncs the URL; added a `popstate` handler

## v12.2.0 — 2026-06-14

feat: the app-bar logo is now a "back to dashboard" button — clicking it (or focusing + Enter/Space) returns to the model-selection screen and reloads it. Added hover/focus affordances and `role="button"`/`aria-label` for accessibility

## v12.1.0 — 2026-06-14

fix: set `app.set('trust proxy', 1)` so the app works correctly behind the cPanel/Passenger→Apache reverse proxy — fixes the `ERR_ERL_UNEXPECTED_X_FORWARDED_FOR` error from express-rate-limit and gives correct client IPs
docs: note that the frontend uses absolute URLs (`/api/...`, `/models/...`) and therefore must be hosted at a domain/subdomain root, not a sub-path (Passenger does not strip a PassengerBaseURI for Node apps)

## v12.0.0 — 2026-06-13

refactor: replace the `better-sqlite3` native module with Node's built-in `node:sqlite` (`DatabaseSync`). `server/db.js` now imports `node:sqlite` and adds a `db.transaction(fn)` shim (BEGIN/COMMIT/ROLLBACK) so existing call sites (authService) are unchanged; all query call sites use positional params and were already compatible. Removes the only compiled dependency that needed a prebuilt binary, eliminating the glibc/compiler problems on the cPanel host (`bcrypt` remains, but it is N-API with a glibc-2.14 prebuilt and loads everywhere)
chore: **requires Node ≥ 22** (where `node:sqlite` is available); added `engines.node >=22`. The production cPanel app runs on Node 24. Drop `better-sqlite3` from dependencies
docs: update CLAUDE.md DB convention (node:sqlite + transaction shim, Node ≥22)

## v11.5.0 — 2026-06-13

feat: deploy.sh gains cPanel conveniences modelled on the bragagenda script — a hardcoded (editable) default target (pedrocan@pedrocandeias.net:/home/pedrocan/public_html/ai-parametric-prosthetic-hand-generator), `--port` for custom SSH ports, `--dry-run`, and a pre-deploy remote backup (sqlite `.backup` of data/app.db + a code tarball into backups/, excluding data/node_modules/backups). rsync now runs over `ssh -p` and still defaults to no `--delete`; the secret-exclusion safety-net and `collect` staging are unchanged. Post-deploy hint now describes the cPanel Node.js App setup instead of `npm start`

## v11.4.0 — 2026-06-13

docs: add a cPanel (Phusion Passenger) deployment path to DEPLOYMENT.md as "Option C" — create-app-first ordering, `server/index.js` startup file, rsync without `--delete` to preserve Passenger's `.htaccess`, panel-based npm install + env vars, and a native-module (bcrypt/better-sqlite3) build caveat

## v11.3.0 — 2026-06-13

feat: parameter help tooltips now show a detailed "Objective / Outcome" explanation for every Flexy Beast parameter (new `help` field per parameter in `models-config.json`). The tooltip prefers `help` and falls back to the short `caption`; the inline caption line is unchanged. Tooltip widened to 320px for the longer text

## v11.2.0 — 2026-06-13

feat: add help tooltips (ⓘ icon) next to every parameter label in the configurator. Hovering or keyboard-focusing the icon shows the parameter's description in a body-level tooltip that is never clipped by the scrollable panel; the existing always-visible caption line is retained

## v11.1.0 — 2026-06-13

chore: deactivate the Paraglider Hand model — moved `models/active/paraglider_hand/` to `models/inactive/paraglider_hand/` and removed its entry from `models-config.json`, so the configurator now only offers Flexy Beast. Files are retained under `models/inactive/` for future reactivation
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

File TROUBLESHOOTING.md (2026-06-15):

# Troubleshooting

## Server won't start

### "JWT_SECRET env var must be set"

The server requires a `JWT_SECRET` of at least 32 characters.

```bash
# Generate one
node -e "console.log(require('crypto').randomBytes(32).toString('hex'))"
# Paste into .env:
JWT_SECRET=<output>
```

If there is no `.env` file yet:
```bash
cp .env.example .env
nano .env
```

### `Cannot find module 'express'` / `Cannot find module 'bcrypt'`

Dependencies are not installed:
```bash
npm install
```

### `Cannot find package 'node:sqlite'` / SQLite errors on startup

The database uses Node's built-in `node:sqlite`, which requires **Node ≥ 22**
(available without a flag on Node 24). Check `node --version` and upgrade if older.

### Port already in use

```bash
PORT=3001 node server/index.js
# or edit PORT= in .env
```

---

## Login / Auth issues

### Login loop — keeps returning to the login screen

1. Clear the `refresh_token` cookie in your browser (DevTools → Application → Cookies)
2. If you changed `JWT_SECRET` since last login, all sessions are invalidated — log in again
3. Check the server logs for `Invalid or expired token` to confirm

### "Invalid credentials" when password is correct

- Username/email lookup is case-insensitive — try the exact value you registered with
- If you created the admin via the CLI script, verify no extra spaces in the password

### "Setup already complete" on POST /api/setup/admin

At least one user already exists in the database. Use the Admin Panel to create more users, or log in with the existing admin account.

### Session expires immediately

- `JWT_SECRET` in `.env` must be stable across restarts. If it is randomly generated each time (e.g. from `start-server.sh` without a `.env`), sessions will not survive a restart.
- Set a permanent value in `.env`.

---

## AI suggestions not working

### "ANTHROPIC_API_KEY not configured" / "OPENAI_API_KEY not configured"

Add the key to `.env`:
```env
ANTHROPIC_API_KEY=sk-ant-...
OPENAI_API_KEY=sk-...
```
Then restart the server (`npm start` / `pm2 restart prosthetic-hand`).

### "AI rate limit exceeded"

You are hitting 10 requests/minute. Wait 60 seconds and try again.

### "AI response was not valid JSON"

The model returned prose instead of JSON. Retry — this is usually transient.

### AI suggest returns 503

The AI provider is down or the key is invalid. Check [status.anthropic.com](https://status.anthropic.com) or the OpenAI status page.

---

## 3D rendering

### 3D viewer blank after selecting a model

1. Open browser DevTools (F12 → Console)
2. Look for errors mentioning `openscad.wasm` or `openscad-worker.js`
3. Ensure those files are present in the project root:
   ```bash
   ls -lh openscad.wasm openscad-worker.js 24c27bd4337db6fc47cb.wasm
   ```
4. Hard-refresh: `Ctrl+Shift+R` (Windows/Linux) or `Cmd+Shift+R` (Mac)

### "Network error" loading the worker

The server must be started from the project root — `node server/index.js` or `npm start`.
Do **not** open `index.html` directly from the filesystem (`file://` URLs block Web Workers).

### Rendering takes forever / timeout

- First render after page load is slower (WASM initialisation, ~3–5s)
- Complex models with high `$fn` values take longer — this is normal
- 30-second timeout is enforced; if it fires consistently, check console for errors

### Model renders but looks wrong

Click **Reset to Defaults** then **Render Preview**.

---

## Saved configurations

### "Cannot save config for another user"

Non-admin users can only save configs for themselves. If you need to save on behalf of a patient, use an admin or tech account.

### Saved config doesn't appear in the dropdown

The config list filters by the currently selected model. Switch to the correct model first, then the dropdown will populate.

### Tech can't see patient's configs

1. Check the patient is assigned to the tech in the Admin Panel → Tech Assignments tab
2. Verify the patient account is active (not suspended)

---

## Admin panel

### Redirected to `index.html` instead of admin panel

Your session either expired or your account doesn't have the `admin` role. Log in as an admin and retry.

### Role change doesn't take effect immediately

The user's active session still has the old role in their JWT. They need to log out and back in (or wait up to 15 minutes for the access token to expire and refresh).

---

## WASM / browser compatibility

### Chrome / Edge

Works best. Ensure DevTools is closed for first render (slight perf impact with DevTools open).

### Firefox

- Web Workers must be enabled: `about:config` → `dom.workers.enabled` = true
- If CSP errors appear in the console, check that `helmet`'s CSP in `server/index.js` includes `blob:` in `workerSrc`

### Safari

May block Service Workers in private browsing mode. Use a normal window.

---

## Database

### DB file missing or corrupted

```bash
# Back up if possible
cp data/app.db data/app.db.bak

# Delete and let the server recreate it
rm data/app.db
npm start
# Re-run first-admin setup in the browser
```

### "SQLITE_BUSY" errors under load

The SQLite WAL mode is enabled by default (`PRAGMA journal_mode = WAL`), which handles concurrent reads well. For high-concurrency production workloads, consider PostgreSQL via a different ORM.

---

## Deployment / production

### `/.env` returns content instead of 404

The Express block is in `server/index.js` before `express.static`. If you have overridden static serving or added a custom handler, check the middleware order.

### Cookies not set on HTTPS

In production (`NODE_ENV=production`) the refresh cookie has `Secure: true`. Ensure your reverse proxy forwards `X-Forwarded-Proto: https`.

### pm2 process keeps restarting

```bash
pm2 logs prosthetic-hand --lines 50
```

The most common causes:
1. Missing `.env` file or missing `JWT_SECRET`
2. Port conflict — set a different `PORT=` in `.env`
3. Missing `node_modules` — run `npm install --omit=dev`

---

## Quick diagnostic checklist

```bash
# Is the server running?
curl -s http://localhost:3000/api/setup/status

# Is .env loaded?
node -e "require('dotenv').config(); console.log(!!process.env.JWT_SECRET)"

# Are WASM files present?
ls -lh openscad.wasm 24c27bd4337db6fc47cb.wasm openscad-worker.js

# Is the database accessible?
node -e "const db=require('./server/db'); console.log(db.prepare('SELECT COUNT(*) AS n FROM users').get())"

# Are sensitive files blocked?
curl -s -o /dev/null -w "%{http_code}" http://localhost:3000/.env          # should be 404
curl -s -o /dev/null -w "%{http_code}" http://localhost:3000/config.json   # should be 404
```

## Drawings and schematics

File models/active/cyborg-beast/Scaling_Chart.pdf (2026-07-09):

## Scaling Chart: Cyborg Beast (3 to 16 years old)

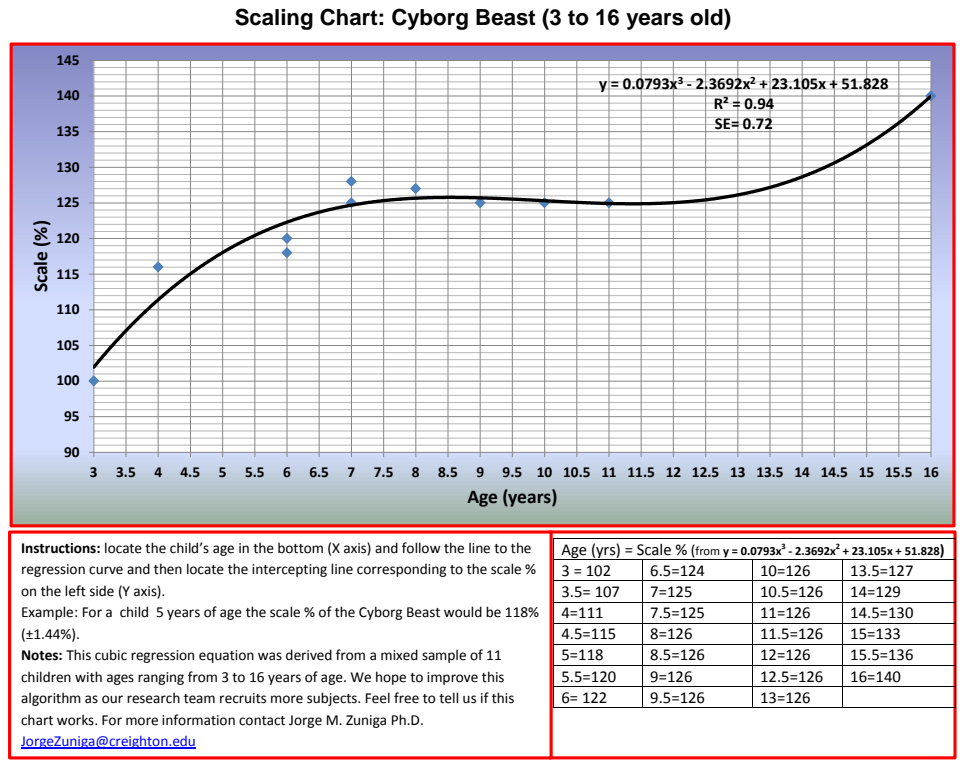
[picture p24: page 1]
Scale (%); Age (years)

Instructions: locate the child’s age in the bottom (X axis) and follow the line to the
regression curve and then locate the intercepting line corresponding to the scale %
on the left side (Y axis).
Example: For a child 5 years of age the scale % of the Cyborg Beast would be 118%
Notes: This cubic regression equation was derived from a mixed sample of 11
children with ages ranging from 3 to 16 years of age. We hope to improve this
algorithm as our research team recruits more subjects. Feel free to tell us if this
chart works. For more information contact Jorge M. Zuniga Ph.D.
JorgeZuniga@creighton.edu

Age (yrs) = Scale % (from y = 0.0793x³

3 = 102 | 6.5=124 | 10=126 | 13.5=127
3.5= 107 | 7=125 | 10.5=126 | 14=129
4=111 | 7.5=125 | 11=126 | 14.5=130
4.5=115 | 8=126 | 11.5=126 | 15=133
5=118 | 8.5=126 | 12=126 | 15.5=136
5.5=120 | 9=126 | 12.5=126 | 16=140
6= 122 | 9.5=126 | 13=126

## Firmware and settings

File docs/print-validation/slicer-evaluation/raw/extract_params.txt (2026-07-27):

################################################################################
# flexy_pla  (flexy_beast_teen_15_print.3mf)  [BAMBU]
################################################################################
  printer_settings_id = 'Bambu Lab A1 0.4 nozzle'
  printer_model = 'Bambu Lab A1'
  nozzle_diameter = ['0.4']
  default_print_profile = '0.20mm Standard @BBL A1'
  layer_height = '0.24'
  initial_layer_print_height = '0.2'
  wall_loops = '2'
  top_shell_layers = '4'
  bottom_shell_layers = '3'
  sparse_infill_density = '15%'
  sparse_infill_pattern = 'grid'
  enable_support = '1'
  support_type = 'tree(auto)'
  support_style = 'tree_organic'
  support_on_build_plate_only = '1'
  support_critical_regions_only = '1'
  support_threshold_angle = '35'
  brim_type = 'auto_brim'
  brim_width = '5'
  brim_object_gap = '0.1'
  filament_settings_id = ['Bambu PLA Basic @BBL A1', 'Bambu PLA Basic @BBL A1', 'Bambu PETG Basic @BBL A1']
  filament_type = ['PLA', 'PLA', 'PETG']
  filament_density = ['1.26', '1.26', '1.25']
  curr_bed_type = 'Textured PEI Plate'
  skirt_loops = '0'
  [plate_1.json] bbox_all(x0,y0,x1,y1)=[50.607648, 66.495239, 208.79021799999998, 187.94826799999998]  footprint=158.18 x 121.45 mm  objects=10  bed=textured_plate  seq=False
  [3dmodel build items] = 10

################################################################################
# phoenix_pla  (unlimbed_phoenix_hand_teen_15_print_project.3mf)  [BAMBU]
################################################################################
  printer_settings_id = 'Bambu Lab A1 0.4 nozzle'
  printer_model = 'Bambu Lab A1'
  nozzle_diameter = ['0.4']
  default_print_profile = '0.20mm Standard @BBL A1'
  layer_height = '0.24'
  initial_layer_print_height = '0.2'
  wall_loops = '2'
  top_shell_layers = '4'
  bottom_shell_layers = '3'
  sparse_infill_density = '15%'
  sparse_infill_pattern = 'grid'
  enable_support = '1'
  support_type = 'tree(auto)'
  support_style = 'tree_organic'
  support_on_build_plate_only = '1'
  support_critical_regions_only = '1'
  support_threshold_angle = '35'
  brim_type = 'auto_brim'
  brim_width = '5'
  brim_object_gap = '0.1'
  filament_settings_id = ['Bambu PLA Basic @BBL A1', 'Bambu PLA Basic @BBL A1', 'Bambu PETG Basic @BBL A1']
  filament_type = ['PLA', 'PLA', 'PETG']
  filament_density = ['1.26', '1.26', '1.25']
  curr_bed_type = 'Textured PEI Plate'
  skirt_loops = '0'
  [plate_1.json] ABSENT
  [3dmodel build items] = 8

################################################################################
# phoenix_petg  (unlimbed_phoenix_hand_teen_15_print_project_PETG.3mf)  [BAMBU]
################################################################################
  printer_settings_id = 'Bambu Lab A1 0.4 nozzle'
  printer_model = 'Bambu Lab A1'
  nozzle_diameter = ['0.4']
  default_print_profile = '0.20mm Standard @BBL A1'
  layer_height = '0.24'
  initial_layer_print_height = '0.2'
  wall_loops = '2'
  top_shell_layers = '4'
  bottom_shell_layers = '3'
  sparse_infill_density = '15%'
  sparse_infill_pattern = 'grid'
  enable_support = '1'
  support_type = 'tree(auto)'
  support_style = 'tree_organic'
  support_on_build_plate_only = '1'
  support_critical_regions_only = '1'
  support_threshold_angle = '35'
  brim_type = 'auto_brim'
  brim_width = '5'
  brim_object_gap = '0.1'
  filament_settings_id = ['Bambu PLA Basic @BBL A1', 'Bambu PLA Basic @BBL A1', 'Bambu PETG Basic @BBL A1']
  filament_type = ['PLA', 'PLA', 'PETG']
  filament_density = ['1.26', '1.26', '1.25']
  curr_bed_type = 'Textured PEI Plate'
  skirt_loops = '0'
  [plate_1.json] bbox_all(x0,y0,x1,y1)=[22.586085, 25.085555, 244.824514, 236.580084]  footprint=222.24 x 211.49 mm  objects=8  bed=textured_plate  seq=False
  [3dmodel build items] = 8

################################################################################
# paraglider_pla  (paraglider_15_teen_prusa_print_profile.3mf)  [PRUSA]
################################################################################
  printer_model = MINIIS
  print_settings_id = 0.20mm SPEED @MINIIS 0.4
  nozzle_diameter = 0.4
  bed_shape = 0x0,180x0,180x180,0x180
  max_print_height = 180
  layer_height = 0.2
  first_layer_height = 0.2
  perimeters = 2
  top_solid_layers = 5
  bottom_solid_layers = 4
  fill_density = 15%
  fill_pattern = grid
  support_material = 0
  support_material_auto = 1
  support_material_buildplate_only = 0
  support_material_threshold = 40
  support_material_style = snug
  raft_layers = 0
  brim_type = outer_only
  brim_width = 0
  skirts = 0
  filament_type = PLA
  filament_settings_id = "Prusament PLA @MINIIS"
  filament_density = 1.24
  filament_diameter = 1.75
  filament_cost = 36.29
  filament_vendor = Prusa Polymers
  printer_notes = Don't remove the following keywords! These keywords are used...
  [model.config] objects=5 volumes=5
  [3dmodel build items] = 5

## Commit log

2025-10-10 feat: Implement OpenSCAD Parameter Editor with model loading and parameter controls
    - Added ParameterEditor class for managing OpenSCAD models and parameters.
    - Implemented configuration loading from JSON file.
    - Created dynamic model selector and parameter controls based on model specifications.
    - Added functionality for rendering previews and exporting OpenSCAD files.
    - Introduced event listeners for user interactions (model selection, parameter changes, etc.).
    - Implemented parameter reset functionality to default values.
    - Added status updates for user feedback.
    feat: Add GLB export functionality for 3D models
    - Implemented exportGlb function to convert IndexedPolyhedron data to GLB fo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
    [box.scad, fingerator.scad, gear.scad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]
2026-03-05 ## v3.3.0 — 2026-03-04
    feat: add Cyborg Beast model set (full hand, palm, finger mid, fingertip) to model selector
    fix: correct double-comma syntax error in paraglider_palm_left.scad pin_coordinates array
    fix: binary STL dependencies (e.g. palm_left_v2_nobox.stl) now fetched as ArrayBuffer and injected into WASM virtual FS
    feat: add renderCall support in models-config.json for library-style SCAD files that define modules but have no top-level call
    ---
    ## v3.2.0 — 2026-02-27
    refactor: redesign anthropometric profiles as population-level reference datasets (not patient records)
    feat: add demographic fields to profiles — group_name, country, gender, age_group, percentile, sample_size,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
    [cyborgbeast07l.scad, cyborgfingermid002.scad, cyborgfingertip002.scad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]
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2026-05-05 ---
    ## v6.1.0 — 2026-05-05
    fix: wrap string parameter values in OpenSCAD quotes when substituting into SCAD code — was rendering part = Cuff1 (unquoted variable) causing all if(Part==...) comparisons to fail with empty geometry
    fix: remove STL-import parts from PeKwawu part selector (IndexFingerEnd, arm segments, Ratchet, WhippleTrees, etc.) — these depend on external .stl files unavailable in the WASM renderer
    chore: rename PeKwawu model to "PeKwawu v1 (Long Residual Limb)"
    chore: move all non-PeKwawu model files to models/old_models/ and remove from models-config.json
    docs: update CLAUDE.md — CHANGELOG update and package.json version bump are now mandatory on every change
    docs: up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
    [anthropometric_cyborgbeast.scad, anthropometric_hand.scad, box.scad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]
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2026-05-21 ## v8.15.0 — 2026-05-20
    feat: main site user menu matches admin style — pill shape, gradient avatar initial, "Hello, {username}" greeting, chevron rotates on open
    fix: dropdown items use consistent 0.8125rem sizing and accent-subtle hover; Log Out item styled red; divider before Log Out
    ## v8.14.0 — 2026-05-20
    feat: admin app bar now shows "Hello, {username}" greeting with avatar initial and chevron dropdown
    feat: dropdown contains Back to App and Log Out actions; closes on outside click
    ## v8.13.0 — 2026-05-20
    fix: role card content padding increased to 28px/24px to match Figma
    fix: role card "Open Dashboard" button uses pill border-radius to match Figma screenshot
    ## v8.12.0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
    [Phoenix_v2_new_supports.stl, Reborn_elbow_pin.stl, Reborn_elbow_pin_cap.stl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]
2026-05-26 ## v9.2.0 — 2026-05-25
    fix: replace fingerpad_solid custom approximation with direct fingertip_pad() invocation — pad preview now shows the exact silicone piece geometry (the positive of the cavity) rather than an independent slab intersection
    fix: remove alpha from pad color() call — pads were semi-transparent at 0.85; now fully opaque so they're clearly visible in the 3D preview
    fix: change show_thermoform default to false — the holey thermoform mesh was overlaid on the palm by default, making the whole hand appear see-through; users can enable it when needed
    ## v9.1.0 — 2026-05-25
    feat: add Flexy Beast parametric prosthetic hand model (adapted from daprice/Flexy-Beast, CC BY-S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
    [UnLimbited Arm V2.2.scad, assembly.scad, config.scad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]
2026-06-06 Split Flexy Beast fingers for printing, rework deploy.sh, repo cleanup
    Flexy Beast:
    - Split each finger into separately exportable base and tip pieces via
    per-segment visibility toggles; update models-config.json parts list so
    the export modal offers a base and a tip per digit.
    Deploy:
    - Rework deploy.sh into collect/deploy modes with a hardened exclude list
    (never ships .env, data/, node_modules) and a post-stage safety check.
    - gitignore deploy/ and deploy.tar.gz.
    - Update README, DEPLOY-QUICKSTART, and DEPLOYMENT to the deploy.sh + npm ci
    flow; document the finger base/tip split.
    Cleanup:
    - Remove old_models/, tools/, kinetic_hand_rh60 assets, Fusion/Phoenix
    reference files, a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
    [All Hinges thickened RH60.STEP, Arm_Guard.stl, Distals.stl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]
2026-06-06 docs: sync ARCHITECTURE/OVERVIEW/QUICK-START with current codebase
    - Replace removed Fingerator/Cyborg/old .scad references with the
    models/active/{flexy_beast,paraglider_hand} layout.
    - Document the /api/anthropometric route, anthropometricImporter service,
    and anthropometric_profiles / password_reset_tokens tables.
    - Add /data/* to blocked-paths and security notes; mention deploy.sh.
    - Update the Quick Start walkthrough + UI sketch to the Flexy Beast,
    including per-finger base/tip STL export.
2026-06-06 feat: connect anthropometric datasets to configurator and AI grounding
    Imported population datasets were stored and browsable but never fed the
    design flow. Wire them in via a single shared mapping module:
    - server/services/profileMapping.js maps profile.measurements (palm.width_mm,
    digits.*.total_length_mm) onto canonical model params, clamped to bounds.
    This is the correct bridge — the importer's geometry_parameters target the
    Kwawu/cyborgbeast design and never matched flexy_beast.
    - Configurator "Population baseline" picker seeds the sliders from any imported
    group (GET /api/anthropometric/options + /:id/model-parameters, requireAuth).
    - AI suggestions grounded: /api/ai/suggest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
2026-06-15 Sync session work (v11.1.0–v14.1.0): i18n, CMS, node:sqlite, cPanel deploy, fixes
    See CHANGELOG.md for the full per-version detail. Highlights:
    - i18n (EN/PT) for the main app + admin panel, with a language switcher (i18n.js, translations.js)
    - Admin-managed footer + Markdown content pages mini-CMS (contentRoutes.js, page.html, markdown.js, footer.js, seed-content.js)
    - Migrate DB driver better-sqlite3 → node:sqlite (Node ≥22); deployable on cPanel/Passenger
    - deploy.sh cPanel support (default target, remote backup, --dry-run, --port); clean URLs (/admin, /pages, /dashboard, /edit)
    - Anthropometric: bulk-import multi_population_hand.csv with age-distinct profiles; 8MB body limit
    - Flex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
    [Normal_Gauntlet_w_Tensioner.stl, fingerator.scad, flexy_beast.scad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]
2026-06-15 i18n: parameters + model text, multilingual CMS pages (v14.2.0–v14.4.0)
    - Configurator model/parameter text translated (EN/PT): models-config.json gains
    name_pt/description_pt + per-parameter label_pt/caption_pt; app.js reads the
    active language via locField(); group headings via translations.js
    - Multilingual content pages: pages table gains language + translation_group
    (auto-migrated); /translate endpoint clones a page into a language; the public
    viewer resolves /pages/<slug>?lang=xx with fallback; admin Pages tab gets a
    Lang column, "+ LANG" Translate buttons, and a language field; page.html gets a
    language switcher
    - Includes concurrent CAD work in the tree (UnLimbited Phoe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
    [UnLimbitedPhoenix.scad]
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2026-06-15 feat: integrate the Paraglider (Flexible Flyer) prosthetic family (v14.10.0)
    Activate paraglider_hand and add 6 variant/accessory models (palm v3,
    two integrated-tensioner palms, tensioner box, thermo gauntlet, UnLimbited
    arm) by Marcus Mendenhall. Supplies the missing palm_left_v2_nobox.stl,
    wires all 7 into models-config.json with canonical anthropometric params,
    per-finger scaling, assembled/print-layout views and show_* toggles, plus
    an Engraving parameter group (EN/PT).
    - fix: patch upstream double-comma array-literal syntax error in the four
    Paraglider palm files; convert v3 palm mesh .3mf -> .stl for WASM import
    - chore: remove the redundant models/inactive/paraglider_hand/ copy
    -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
    [UnLimbited_Arm_paraglider_v2.1.scad, fingerator.scad, gripper_box_pieces.scad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]
2026-06-15 refactor: consolidate Paraglider into one model with component/palm_style options (v14.11.0)
    Collapse the 7 Paraglider dropdown entries into a single `Paraglider · Hand`
    model. A `component` selector (Hand / Tensioner Box / Thermo Gauntlet /
    UnLimbited Arm) and `palm_style` selector (Phoenix Reborn / Unlimbited v3)
    replace the separate entries.
    Each component's OpenSCAD source is namespaced (every internal identifier
    prefixed, top-level geometry wrapped into a `*_main()` module) so the
    near-duplicate files coexist in one dispatcher via `include`, driven by the
    Hand's shared anthropometric inputs. New scripts/namespace_scad.py generates the
    bundles; each was verified byte-faithful against i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
    [UnLimbited_Arm_paraglider_v2.1.scad, palm_left_v2_nobox.stl, palm_v3.stl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]
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2026-06-16 fix: Flexy Beast per-part STL export no longer bundles the gauntlet in every part (v14.13.0)
    The gauntlet is gated by show_gauntlet in the SCAD but was missing from the
    model's `parts` list, so the per-part export override (which only toggles off
    variables belonging to a declared part) never set it false — every exported
    finger/palm STL silently included the forearm cuff. Added the gauntlet as its
    own printable part, which excludes it from other parts' exports and lets it be
    exported on its own.
2026-06-22 feat: appbar help button opens a help popover with tips & docs (v14.14.0)
    Replace the blocking alert() on the appbar "?" button with an anchored
    help popover: a 6-step getting-started walkthrough plus a "More help"
    section with collapsible documentation (anatomical field guide, keyboard/
    viewer controls) and a support link. Closes on outside click or Esc.
    Fully localised in EN + PT.
2026-06-25 feat: lay STL exports flat on the print bed for Paraglider & Flexy Beast (v14.15.0)
    STL export now seats every part on Z=0 and tiles parts flat instead of
    exporting the assembled prosthetic pose, which is unprintable. Preview
    stays assembled; bed layout applies only on export.
    - app.js: _dropStlToBed (translate mesh so min-Z=0), _mergeBinaryStl
    (concat binary STL payloads for the whole-model plate), _applyExportLayout
    (inject per-model SCAD overrides), _renderSelection wiring.
    - flexy_beast.scad: print_layout param + printlayout() module tiling parts flat.
    - paraglider_hand.scad: drop the rotate([0,180,0]) flips that pushed fingers
    below the bed; add pins to the print branch.
    - models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
    [flexy_beast.scad, paraglider_hand.scad]
2026-06-28 fix: anthropometric grounding matcher + Paraglider palm scaling
    Two fixes surfaced by the AI-sizing → STL export simulations.
    Grounding (v14.16.0): findBestProfileMatch no longer anchors every patient on
    ANSUR I Male. The male token 'm,' was a substring of the units "mm,"/"cm,", so
    any measurement read as male, and gender/age parsing was English-only. Now
    Unicode word-boundary multilingual (EN/PT/ES) tokens, "anos"/"años" age parsing,
    and numeric age_group ("7","18-30","80+") bucketed to child/adult/elderly with
    age proximity. Optional LLM extraction (extractPatientAttributes, claude-haiku-4-5)
    anchors free-text descriptions, gated to run only when the deterministic parse is
    incomplete a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
    [paraglider_hand.scad]
2026-06-29 fix: clamp UnLimbited Phoenix print scale to 100-160% on both paths
    HandPerc_override has a declared range of [0:160], but only 0 (auto) and
    100-160 (direct) are meaningful — the 1-99 band was a dead zone with no floor,
    bypassing the 100% minimum that palm_breadth_mm (clamped to 100-160%) enforces.
    The AI-sizing simulation hit this: a child profile returned HandPerc_override=76,
    scaling the Phoenix mesh to 76% (62 mm) — below the supported minimum, and
    inconsistently with the woman profile (floored to 100%). The override branch now
    applies the same max(100, min(160, ...)) clamp, so neither path goes sub-100%.
    Adds docs: the Phoenix AI-sizing dimensional report (docs/phoenix-ai-sim/) and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
    [UnLimbitedPhoenix.scad]
2026-06-29 chore: add /cpd command (commit → push → deploy with safety checks)
    Encapsulates the release workflow: review diff, guard against stray scratch and
    missing CHANGELOG/version bumps, commit intended files only, push, dry-run +
    deploy via deploy.sh, restart Passenger only when server/** changed, health-check.
2026-06-29 docs: pt-PT validation study + §6 cross-model geometric validation
    Translate docs/ai_anthropometric_validation.md to European Portuguese (thesis
    register; code, parameter/function names, paths, numbers and tables preserved).
    Add §6 "Experimento 3 — Cross-Model Geometric Validation (AI → STL)" that
    synthesises the three per-model AI-sizing→STL runs: applied parameters and palm
    scale ratios across Flexy Beast / Paraglider / Phoenix, fidelity to the source
    geometry, the three defects found and fixed (grounding v14.16.0, Paraglider palm
    v14.17.0, Phoenix override v14.18.0), and model-selection guidance. Subsequent
    sections renumbered (7–10); the stale "§8" cross-reference now points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
2026-07-10 fix: seat Cyborg Beast fingers on the palm knuckle hinge line (v14.35.0)
    Each finger's proximal fingermid hinge hole floated 4.6–7.1 mm past the
    palm knuckle hinge holes, so the assembly pin couldn't pass through both.
    The original per-finger y-offsets were tuned for the design's small native
    `len` values; the anthropometric layer drives `len` much wider and the
    fingermid hole spacing (11.5 + len/3) tracks it. New place_finger() module
    uses yoff = 9.5 + len/3, landing the proximal hole on the knuckle line
    (y=27) for every finger and length. Verified numerically + visually.
    Also: fetch .scad model source + text deps with { cache: 'no-cache' } so
    geometry edits reach returning browsers (sam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
    [cyborg_beast.scad, cyborgbeast07l.scad, flexy_beast.scad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]
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2026-07-10 fix: Phoenix assembled preview shows palm + fingertips (v14.41.0)
    The v14.36.0 assembled Phoenix view rendered fine headless but lost the
    palm and the four distal (fingertip) segments in the browser. The
    in-browser preview uses the manifold backend, which silently drops any
    mesh that fails PolySet->Manifold conversion; the stock
    Phoenix_Thermo_Palm_2 (palm) and Phoenix_Fingers_Left (distals) are
    non-manifold (self-intersections / edges shared by >2 faces). They
    survive when printed one part at a time (no boolean) but the assembly's
    top-level union forces conversion, dropping both and leaving only the
    manifold proximals.
    Fix: ship watertight voxel-remeshed manifold copies
    (phoenix_palm_manif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
    [cyborg_beast.scad, phoenix_assembly.scad, phoenix_fingers_manifold.stl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]
2026-07-10 fix: Phoenix preview — restore palm/fingertip definition (v14.42.0)
    The v14.41.0 manifold fix voxel-remeshed the palm and fingertips at a
    coarse pitch (palm 1.25mm), which made them render under the browser's
    manifold backend but stripped all surface detail (blobby look).
    Regenerate at fine pitch (palm 0.4mm, fingers 0.32mm) then reduce with
    manifold-preserving decimation (manifold3d.simplify, 0.11-0.14mm tol) —
    ~38k/26k tris, detail recovered while staying watertight-manifold. Also
    convert them from binary-STL imports to embedded polyhedron() modules
    (phoenix_preview_meshes.scad), matching how the rest of the model stores
    geometry: one 1.9MB .scad dependency replaces the two ~3MB STL d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
    [phoenix_assembly.scad, phoenix_fingers_manifold.stl, phoenix_palm_manifold.stl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]
2026-07-10 feat: Cyborg Beast palm liner + gauntlet refit + thumb match to reference STLs (v14.44.0)
    - Palm gains the Flexy Beast thermoformable perforated liner (show_thermoform +
    color_thermoform, clipped to the palm interior), rendered in assembled + print
    layout with a Palm liner printable part.
    - Gauntlet: seat corrected to the real palm wrist-pin axis (y=-27, z=5.5) so its
    wings meet the palm wings; width decoupled from depth so the prongs always nest
    against the wrist fins (X locked to the palm) while depth still tracks
    wrist_circumference_mm; new defaults gauntlet_tilt=0, gauntlet_length_scale=0.7.
    - Thumb: measured against the original reference STLs (models/active/cyborg-beast/
    st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
    [cyborg_beast.scad]
2026-07-10 feat: Phoenix per-part toggles replace the part selector (v14.45.0)
    Drop the `part` dropdown on the UnLimbited Phoenix model; every part now
    has its own always-visible toggle (show_palm, show_fingers, show_thumb,
    show_pins, show_gauntlet, show_tensioner) plus a print_layout switch
    (assembled seated preview <-> flat print-bed layout for STL export),
    matching the Cyborg Beast / Flexy Beast pattern (exportLayout:
    {print_layout:true}, Visibility group). The assembled view and print
    layout are both gated by the toggles, scaled uniformly by HandPerc and
    mirrored for a right hand. Full EN/PT captions + help.
    Also swap the Phoenix preview meshes from the v14.42.0 voxel remesh
    (manifold but blobby)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
    [UnLimbitedPhoenix.scad, cyborgbeast07l.scad, phoenix_assembly.scad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]
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2026-07-10 feat: Phoenix per-finger parametric length (index..pinky)
    Each finger's length is now adjustable without distorting its pin holes.
    The Phoenix meshes are fixed, so a finger is lengthened by splitting its
    column at the hole-free shaft, keeping the hinge (hole) zones unscaled,
    stretching only the shaft, and shifting the far end out — the pin holes
    stay perfectly round and printable.
    New params (index/middle/ring/pinky): <finger>_finger_length_mm (total
    MCP->tip, Anthropometric) + <finger>_base_length_mm (proximal MCP->PIP,
    Segment split). REF native = 72 total / 31 base, so defaults render
    identically to the stock finger. The PIP pin and fingertip follow the
    lengthened proximal automaticall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
    [UnLimbitedPhoenix.scad, phoenix_assembly.scad]
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2026-07-11 chore: release v14.51.0 — pec Phoenix STEP part swap + single-file palm
    v14.50.0: replace the hand-fitted Tensioner_Block / Tensioner_Pins /
    Snap_Pins_without_Labels reconstructions with the step2scad STEP-measured
    phoenix_* parts shared with the UnLimbited Phoenix model; the (gitignored)
    _assembly.scad now seats the real snap/clip pins + cup washers.
    v14.51.0: fuse the five Palm_left_V2_* part files inline into
    Palm_left_V2.scad with per-part Customizer checkboxes.
    [Palm_left_V2.scad, Palm_left_V2_fins.scad, Palm_left_V2_rings.scad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]
2026-07-12 feat: release v14.61.0 — pec Phoenix parametric palm/fingers + laterality-first configs
    Uncommitted work spanning v14.52.0–v14.61.0:
    - pec Phoenix palm (Palm_left_V2.scad): fully parametric dorsal shell +
    floor (Cyborg Beast hull technique), parametric knuckles with surface
    smoothing, paraglider-style D cable channels, per-part colours, thumb
    mount artifact fixes, floor tucked under knuckle/thumb/wrist curves
    - pec Phoenix fingers: Proximals_v2 (IoU 0.965) + Distals_v3 (IoU 0.96+)
    fingerator-idiom reworks, assembled in new _assembly_v2.scad
    - models-config.json: laterality (left/right) moved to first parameter
    on all four platform models (v14.52.0)
    - docs/pec-phoenix-hand/: th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
    [Distals_v3.scad, Palm_left_V2.scad, Palm_left_floor.scad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]
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2026-07-13 feat: pec Phoenix palm fully parametric — ghost-free, watertight (v14.68.0)
    Palm_left_V2.scad refinement wave (v14.62–v14.68):
    - Direct inclined ramps at both rims (KN_RAMPS front, WR_RAMPS back);
    PART 6 wrist_back rebuilt parametric (WBAND + cuff inclines).
    - Thumb mount rebuilt fully parametric (thumb_dome/body/slot/fin/junction)
    → import(ghost_stl) now only in the show_ghost overlay; the whole palm
    is parametric. Full model trimesh-watertight, OpenSCAD NoError.
    - Cable channels no longer sealed by the dorsal fins; fins re-measured.
    - Thumb mesh simplified (−36% facets) and dorsal crown de-creased.
    [Palm_left_V2.scad]
2026-07-14 feat: release v14.71.0 — shared Flexy/Cyborg gauntlet, thesis eval suite, fixture sync
    Bundles three pending, CHANGELOG-documented releases:
    - v14.69.0: thesis evaluation test suite (test/thesis/) — REP/ROB/ACC
    campaigns; env seams HANDFAB_DB_PATH (server/db.js) and
    LOGIN_RATE_LIMIT_MAX (authRoutes.js), both prod-safe no-ops when unset.
    - v14.70.0: Flexy Beast now uses the same forearm gauntlet as the Cyborg
    Beast (shared Cyborg palm/wrist hinge). Inlined primitive cuff removed;
    gauntlet.scad copied in and sized by wrist_circumference_mm (canonical,
    so profiles auto-size it). Verified with local OpenSCAD renders.
    - v14.71.0: sync test/thesis frozen-configs.json to the new Flex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
    [flexy_beast.scad, gauntlet.scad]
2026-07-14 refactor: coherent parameter interface + laterality/view renames (v14.72.0)
    - Canonical parameter group order across all four models (Component →
    Anthropometric → Segment split → Hardware → Gauntlet → Options →
    Visibility → Colors → Arm); merged Cyborg 'Palm liner' into Options.
    Config-only reorder — names, values and behaviour unchanged.
    - Rename Phoenix laterality LeftRight (enum) → mirrored (bool), matching
    the other three models (SCAD + config). No saved-config migration
    needed: laterality is UI-only and skipped in applySuggestions.
    - Rename Paraglider view toggle show_assembled → print_layout (inverted),
    matching Cyborg/Phoenix; exportLayout → {print_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
    [UnLimbitedPhoenix.scad, paraglider_hand.scad]
2026-07-23 feat: Phoenix washer visibility toggle + washer/thumb-pin seating (v14.76.0)
    - show_washers: wrist-pin cup washers split out of show_tensioner into their
    own Visibility checkbox (SCAD + models-config EN/PT + print-bed layout)
    - washers re-seated per-washer (WASHER_POS/WASHER_ROT now arrays)
    - thumb pins: PIN_OFF_THUMB zeroed so MCP/PIP pins sit exactly on the part
    hole axes; PIN_FLIP_THUMB=[1,0] turns the rectangular snap-pin head into
    the palm saddle's rectangular recess
    [UnLimbitedPhoenix.scad, phoenix_assembly.scad]
2026-07-27 feat: SSH-less FTPS deploy mode + Phoenix wrist/thumb pin seating (v14.77.0)
    - deploy.sh ftp: collect → content-hash manifest → incremental FTPS upload
    via one curl config (creds in git-ignored .ftp-deploy.conf, template in
    ftp-deploy.conf.example; per-host manifest in .deploy-state/). Never
    deletes remotely, never touches live data/. New collect excludes:
    .slicer-work/, dist-*.zip, docs/print-validation/, FTP conf + state.
    - Phoenix: wrist pins seated on gauntlet boss holes (PIN_OFF_WRIST ±2 mm X,
    flips [0,1]); thumb PIP pin flipped + 0.5 mm drop; new zeroed PIN_ROT_*
    per-pin rotation hooks.
    - docs: slicer-evaluation evidence suite (Annex D) + previously documented
    print-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
    [cyborg_beast_teen_15_print_project.3mf, extract_params.txt, phoenix_assembly.scad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]
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

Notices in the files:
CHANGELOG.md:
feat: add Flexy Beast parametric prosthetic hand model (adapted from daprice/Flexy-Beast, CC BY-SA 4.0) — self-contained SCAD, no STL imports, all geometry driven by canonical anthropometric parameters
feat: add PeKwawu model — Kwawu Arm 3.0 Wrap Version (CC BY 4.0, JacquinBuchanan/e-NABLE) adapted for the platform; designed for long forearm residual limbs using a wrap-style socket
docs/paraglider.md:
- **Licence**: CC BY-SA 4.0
